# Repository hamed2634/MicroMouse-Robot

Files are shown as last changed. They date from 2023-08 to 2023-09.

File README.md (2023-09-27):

# Micromouse Project 🤖

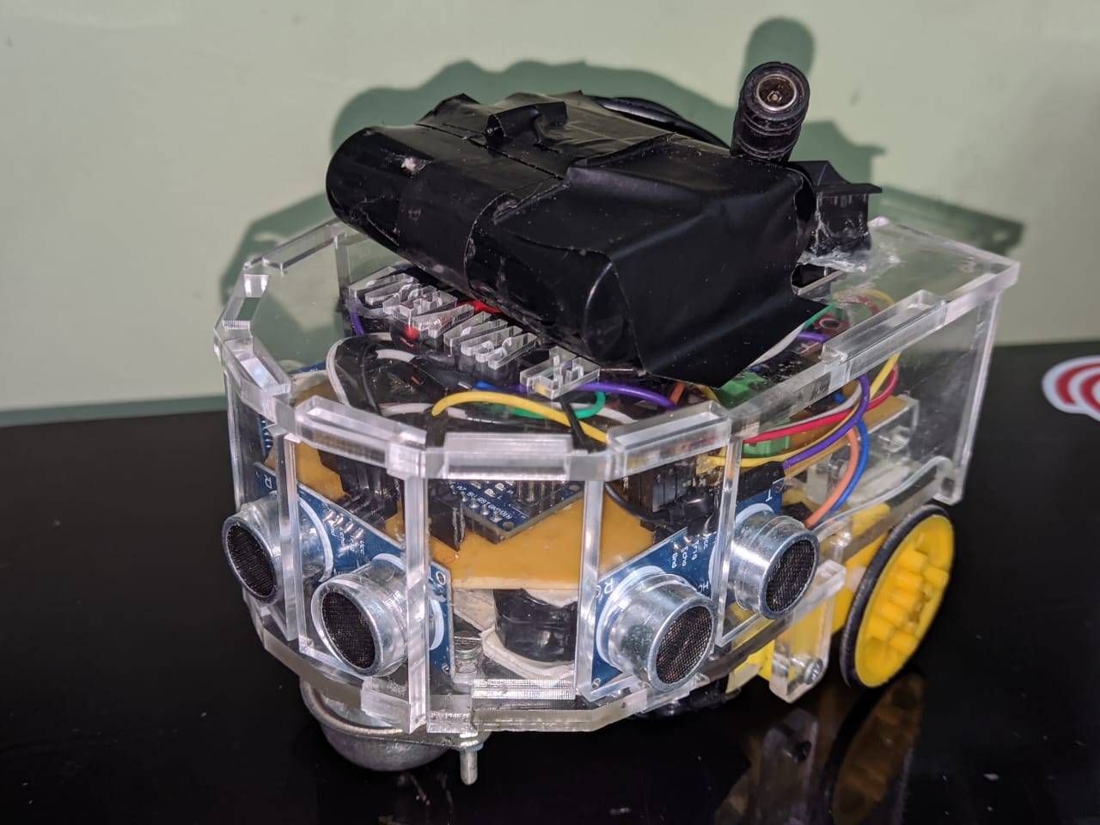
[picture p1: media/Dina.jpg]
Micromouse Robot


Welcome to the Micromouse project repository! This project showcases a small autonomous robot designed for maze navigation. Explore this project if you're interested in robotics and autonomous systems.

## Table of Contents
- [Hardware Components](#hardware-components-%EF%B8%8F)
- [Software](#software-)
  - [Controlling the Robot](#controlling-the-robot-)
  - [Algorithms](#algorithms-)
- [Team](#team-)
- [Installation](#installation-)
- [Contributing](#contributing-)
- [Contact](#contact-)

## Hardware Components 🛠️

The Micromouse project utilizes the following hardware components:

### PCB (Printed Circuit Board) 🧩
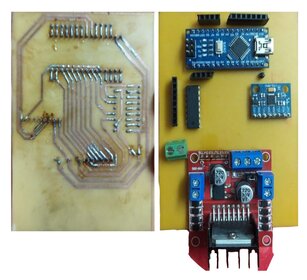
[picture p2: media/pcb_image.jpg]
PCB


The central control hub that connects and manages all other components.

You can find all details and schematic [Here](https://oshwlab.com/om4rr/micromouse).

### Ultrasonic Sensor 🦇
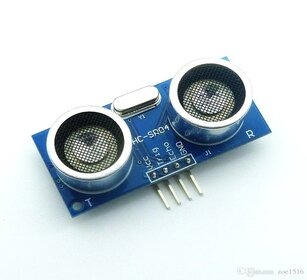
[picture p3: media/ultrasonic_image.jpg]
Ultrasonic Sensor


Measures distances and detects obstacles for navigation.

### IR Sensor (Infrared Sensor) 🕵️
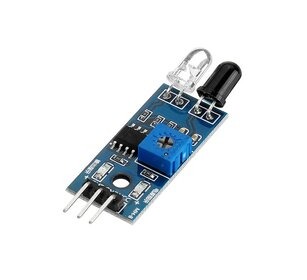
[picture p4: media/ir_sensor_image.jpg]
IR Sensor


Detects lines and walls for precise navigation in mazes.

### Optical Encoder 🔍
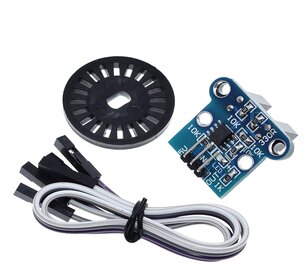
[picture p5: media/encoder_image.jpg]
Optical Encoder


Tracks wheel movements for accurate control.

### Wheels 🚗
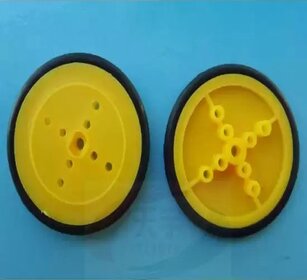
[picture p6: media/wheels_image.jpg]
Wheels and Chassis


The wheels of the robot.

### 3D Design 🖨️

We have designed a custom 3D chassis for the robot using Fusion 360. Here's a photo of our 3D design:

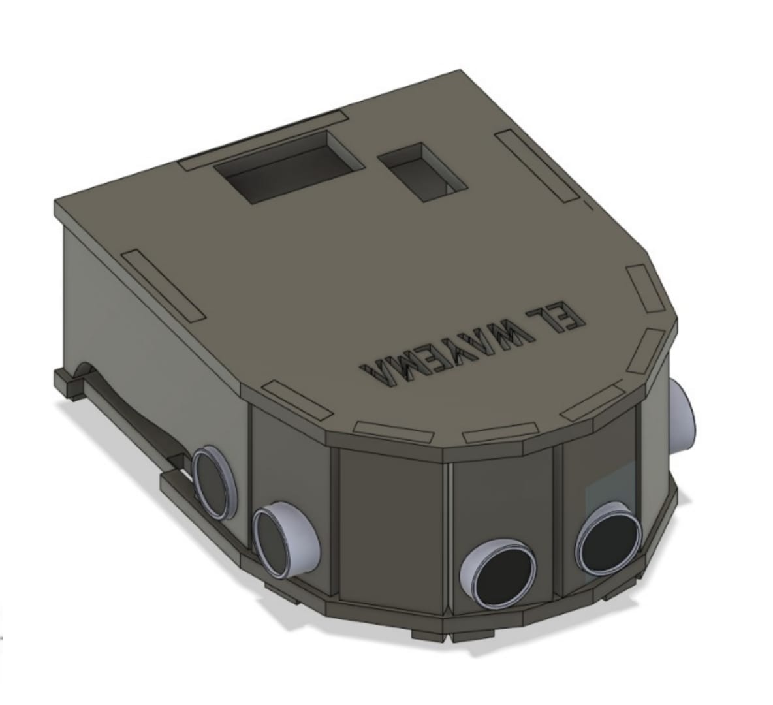
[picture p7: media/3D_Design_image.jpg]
3D Design


For More Photos click [Here](Design/images)

### Bluetooth Module 📶
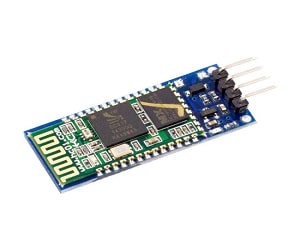
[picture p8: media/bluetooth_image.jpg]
Bluetooth Module


Allows remote debugging and control for monitoring the robot.

### Motors 🔄
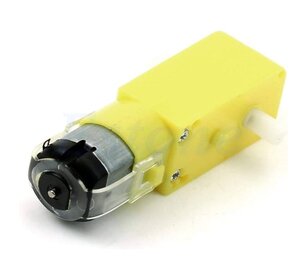
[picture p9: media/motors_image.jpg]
Motors


Drive the wheels for movement.

### Freewheel (Caster Wheel) 🎡
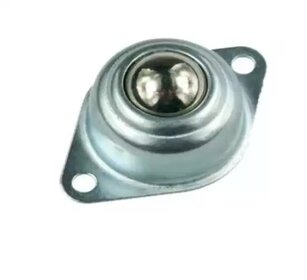
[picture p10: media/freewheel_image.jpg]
Freewheel


Provides stability and maneuverability during turns.

### Gyroscope (MPU6050) 🧭
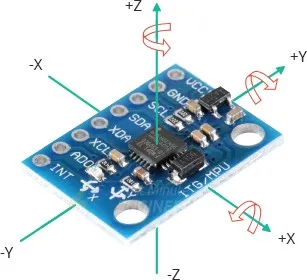
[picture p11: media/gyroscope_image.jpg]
Gyroscope


Measures angles and helps maintain orientation for accurate navigation.

## Software 🧾

### Controlling the Robot 🎮

#### Angle Control with PD System 📐

We've implemented a PD (Proportional-Derivative) control system for angle control using the Gyroscope (MPU6050) as the feedback element. The primary goal of this system is to keep the robot moving in a straight line and execute precise 90-degree turns when needed.

- **Proportional (P):** The proportional part of the controller ensures that the desired angle remains static, allowing the robot to move in a straight line.

   Functionality: When P is adjusted, it affects how quickly the robot corrects deviations from a straight path.

- **Derivative (D):** The derivative part helps fine-tune the turning process.

   Functionality: Tuning D affects how the robot responds to deviations in the angle, contributing to stable and precise turns.

For graphs and visualizations of the tuning process, please click [Graphs](Testing/PID_CALC/Graphs) to access the response graphs.

#### Sensor Reading 📡

To navigate the maze effectively, the robot continuously reads sensors located in every cell. Here's how the sensors work:

- **Ultrasonic Sensors:** These sensors detect obstacles, specifically walls, by measuring distances. This information helps the robot avoid collisions and navigate around maze walls.

- **IR Sensors (Infrared Sensors):** While the robot is designed to move in a straight line, minor alignment issues can occur. The IR sensors play a crucial role in detecting deviations from a straight path. If an IR sensor reads a signal, it indicates that the robot is getting too close to a wall.

   Functionality: In response to IR sensor readings, we make minor adjustments to the desired angle, typically by 5 degrees, to correct the alignment and maintain a straight path.

By combining precise angle control and sensor readings, our robot can successfully navigate the maze with accuracy and efficiency.

### Algorithms 🧠

The general idea for the algorithm is that it discovers the whole maze using the flood-fill algorithm and collects the data needed to configure the shortest path using BFS.
The code is provided with comments to explain in detail this approach [Algorithm](Optimised_Algorithm/floodfill/floodfill.cpp).

#### Maze Simulation 🌀

You can watch a maze simulation in action below:

Maze Simulation (https://github.com/hamed2634/MicroMouse-Robot/assets/52867472/5dad4e3b-37f2-4e1f-a091-5508377ebc72)

## Team 👥

Meet the team members who contributed to this project:

- **[Hamed](https://github.com/Hamed2634):** Responsible for controlling the robot.

- **[3bkareem](https://github.com/3bkareem):** Responsible for algorithm development.

- **[om4rrr](https://github.com/om4rrr):** Responsible for PCB design and assembling hardware.

- **[Kareem](https://github.com/UwUKareem):** Responsible for 3D design.

## Installation 📥

1. You can download the latest version of the Micromouse project as a ZIP file by clicking [here](link_to_zip_file.zip).

## Contributing 🤝

While this project primarily serves as a showcase, we welcome suggestions and improvements. Feel free to create issues or send pull requests.

## Contact 📧

For inquiries or to get in touch, you can reach us at [hamed.mohamed26324@gmail.com]. Enjoy exploring the Micromouse project! 🤖🚀

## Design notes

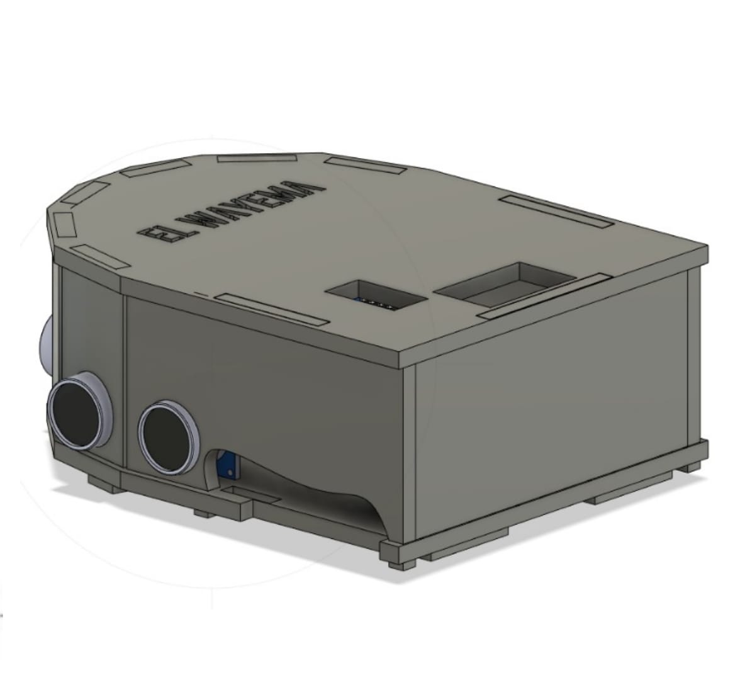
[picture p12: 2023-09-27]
Design/images/3D_Design_1_image.jpg

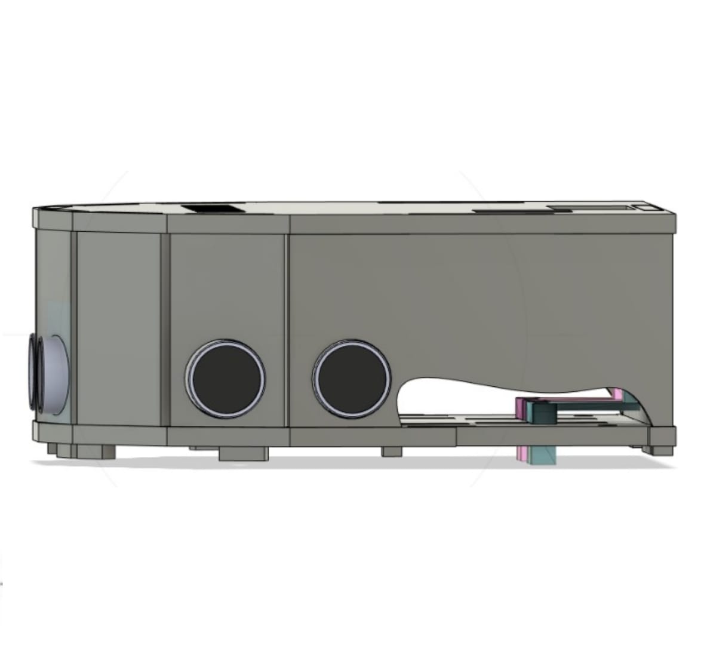
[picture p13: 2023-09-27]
Design/images/3D_Design_2_image.jpg

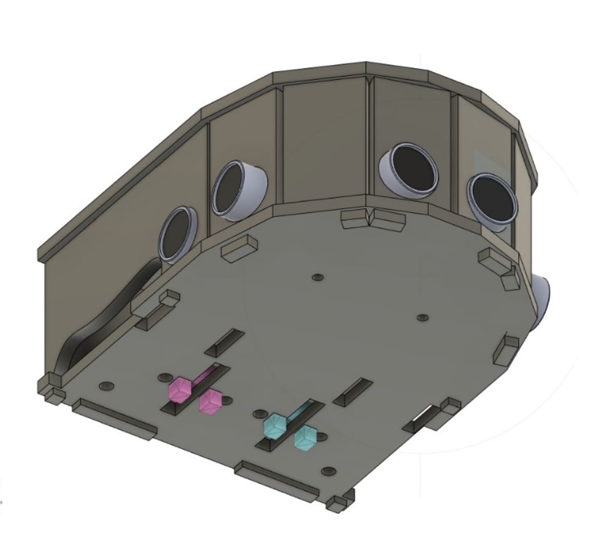
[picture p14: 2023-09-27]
Design/images/3D_Design_4_image.jpg

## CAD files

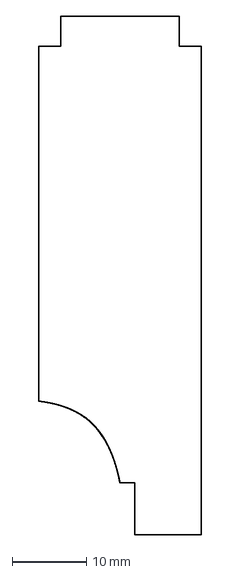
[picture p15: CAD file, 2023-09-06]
Design/side 4.dxf
22.0 x 70.0 mm

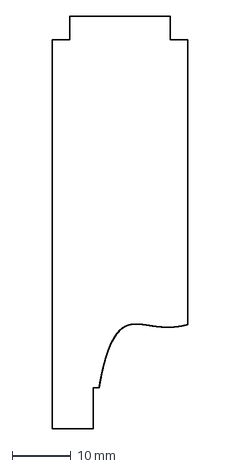
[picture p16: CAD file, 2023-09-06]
Design/side 3.dxf
23.0 x 70.0 mm

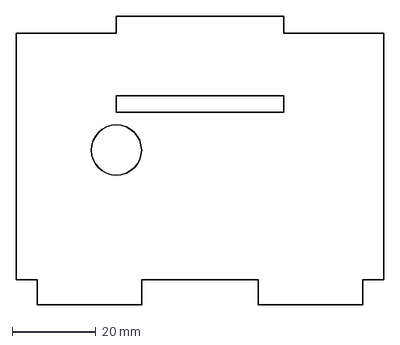
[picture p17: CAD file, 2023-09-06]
Design/back.dxf
88.0 x 69.0 mm

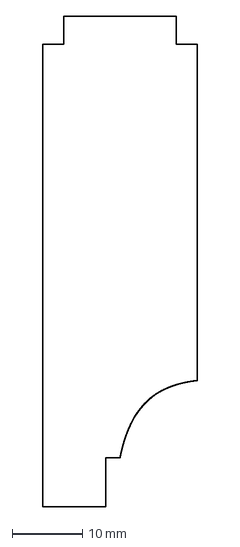
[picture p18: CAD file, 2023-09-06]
Design/side 5.dxf
22.0 x 70.0 mm

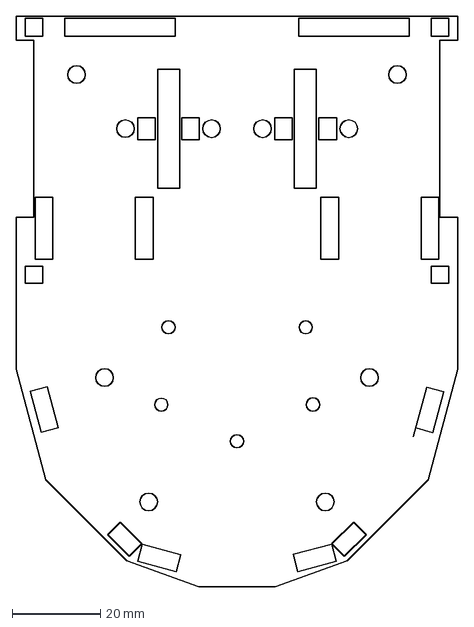
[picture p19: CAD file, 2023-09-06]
Design/frist floor .dxf
100.0 x 129.2 mm

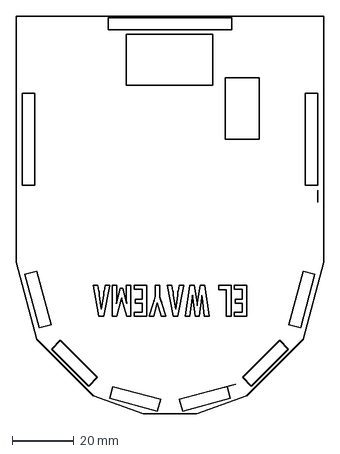
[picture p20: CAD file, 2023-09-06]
Design/third floor.dxf
100.0 x 129.2 mm

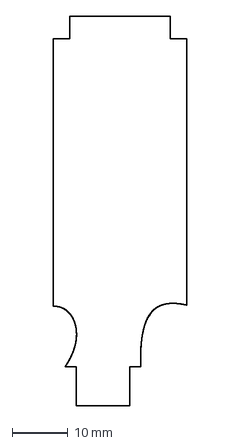
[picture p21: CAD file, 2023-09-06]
Design/side 7.dxf
24.0 x 70.0 mm

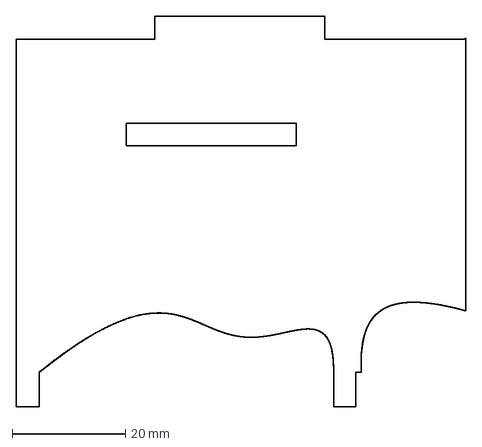
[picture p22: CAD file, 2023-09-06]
Design/side 8.dxf
79.5 x 69.0 mm

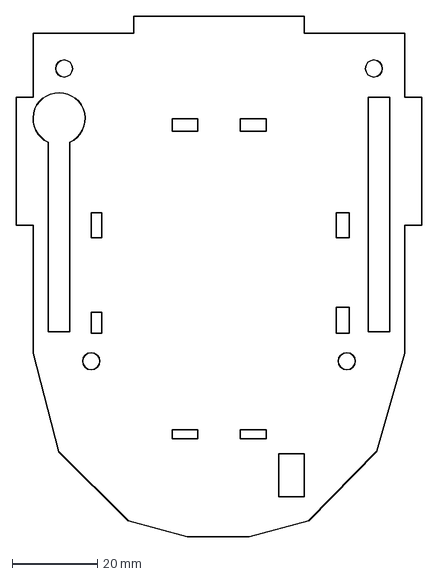
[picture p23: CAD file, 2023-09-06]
Design/second floor.dxf
95.0 x 122.0 mm

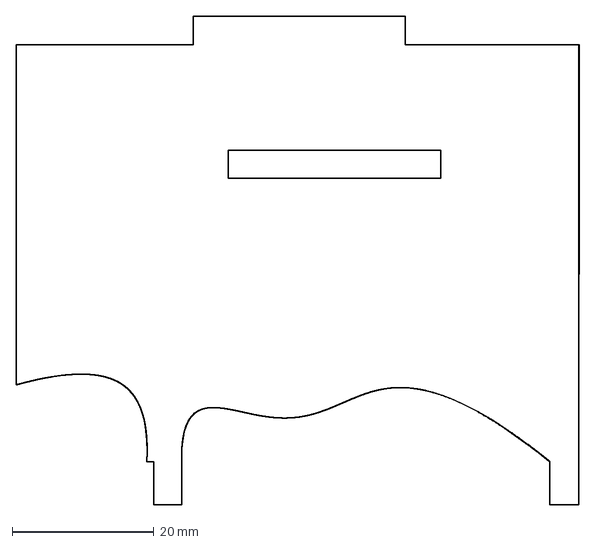
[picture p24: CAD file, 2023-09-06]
Design/side 1.dxf
79.5 x 69.0 mm

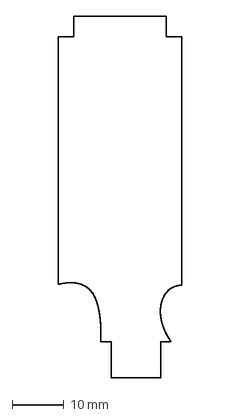
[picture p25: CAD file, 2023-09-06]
Design/side 2.dxf
24.0 x 70.0 mm

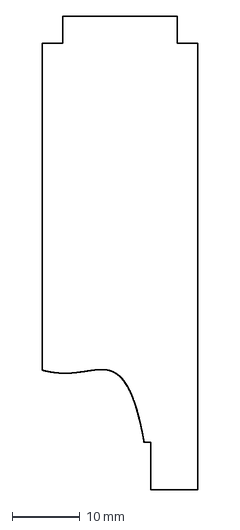
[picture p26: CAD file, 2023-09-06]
Design/side 6.dxf
23.0 x 70.0 mm

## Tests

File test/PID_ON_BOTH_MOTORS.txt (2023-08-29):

  float RightKp = 7.1000, LeftKp = 5.1000, RightKd = 100.00000, LeftKd = 100.00000;
  float DesiredDistance = 100.00;
  float RightDistanceError = DesiredDistance - RightCount * 21.50/40.00;
  float LeftDistanceError = DesiredDistance - LeftCount * 21.50/40.00;
  float RightOutput = RightKp * RightDistanceError + RightKd * (RightDistanceError - LastRightDistanceError);
  float LeftOutput = LeftKp * LeftDistanceError + LeftKd * (LeftDistanceError - LastLeftDistanceError);

  LastRightDistanceError = RightDistanceError;
  LastLeftDistanceError = LeftDistanceError; 

  AddToRightSpeed(RightOutput);
  AddToLeftSpeed(LeftOutput);

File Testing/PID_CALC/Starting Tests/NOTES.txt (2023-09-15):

Kp
1 ---> UNstaple
0.1 --> stable and slow
0.5 --> unstable over time
0.12->stable

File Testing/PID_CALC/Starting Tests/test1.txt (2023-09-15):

0.00 30.00 30.00
0.00 60.00 60.00
0.00 90.00 90.00
0.00 120.00 120.00
0.00 150.00 150.00
0.00 180.00 180.00
0.00 210.00 210.00
0.00 240.00 240.00
0.00 255.00 255.00
0.00 255.00 255.00
0.00 255.00 255.00
0.00 255.00 255.00
0.00 255.00 255.00
0.00 255.00 255.00
0.00 255.00 255.00
-0.02 255.00 255.00
-0.03 255.00 255.00
-0.06 255.00 255.00
-0.07 255.00 255.00
-0.09 255.00 255.00
-0.11 255.00 255.00
-0.12 255.00 255.00
-0.14 255.00 255.00
-0.15 255.00 255.00
-0.17 255.00 255.00
-0.19 255.00 255.00
-0.21 255.00 255.00
-0.21 255.00 255.00
-0.21 255.00 255.00
-0.21 255.00 255.00
-0.21 255.00 255.00
-0.21 255.00 255.00
-0.21 255.00 255.00
-0.21 255.00 255.00
-0.21 255.00 255.00
-0.21 255.00 255.00
-0.21 255.00 255.00
-0.22 255.00 255.00
-0.24 255.00 255.00
-0.25 255.00 255.00
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

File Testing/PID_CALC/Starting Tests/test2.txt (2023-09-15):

04:02:09.843 12.86 ‑17.46 17.46 450.00
04:02:09.846 11.53 ‑9.00 9.00 450.00
04:02:09.880 10.22 ‑0.51 0.51 450.00
04:02:09.880 8.92 7.99 ‑7.99 450.00
04:02:09.881 7.37 18.30 ‑18.30 450.00
04:02:09.881 6.35 24.96 ‑24.96 450.00
04:02:09.881 5.11 33.30 ‑33.30 450.00
04:02:09.884 3.90 41.49 ‑41.49 450.00
04:02:09.884 2.74 49.46 ‑49.46 450.00
04:02:09.888 1.61 57.26 ‑57.26 450.00
04:02:09.888 0.52 64.86 ‑64.86 450.00
04:02:09.915 ‑0.53 94.86 ‑34.86 450.00
04:02:09.915 ‑1.72 103.31 ‑43.31 450.00
04:02:09.915 ‑2.65 110.00 ‑50.00 450.00
04:02:09.918 ‑3.51 116.28 ‑56.28 450.00
04:02:09.918 ‑4.31 122.13 ‑62.13 450.00
04:02:09.947 ‑5.03 127.52 ‑67.52 450.00
04:02:09.947 ‑5.67 132.43 ‑72.43 450.00
04:02:09.949 ‑6.22 136.73 ‑76.73 450.00
04:02:09.949 ‑6.70 140.51 ‑80.51 450.00
04:02:09.951 ‑7.09 143.77 ‑83.77 450.00
04:02:09.953 ‑7.47 146.94 ‑86.94 450.00
04:02:09.953 ‑7.71 149.14 ‑89.14 450.00
04:02:09.981 ‑7.86 150.80 ‑90.80 450.00
04:02:09.981 ‑7.95 151.97 ‑91.97 450.00
04:02:09.982 ‑7.95 152.52 ‑92.52 450.00
04:02:09.982 ‑7.89 152.62 ‑92.62 450.00
04:02:09.985 ‑7.75 152.21 ‑92.21 450.00
04:02:09.986 ‑7.54 151.29 ‑91.29 450.00
04:02:09.986 ‑7.21 149.49 ‑89.49 450.00
04:02:10.027 ‑6.88 147.60 ‑87.60 450.00
04:02:10.027 ‑6.48 145.26 ‑85.26 450.00
04:02:10.027 ‑6.01 142.42 ‑82.42 450.00
04:02:10.027 ‑5.49 139.18 ‑79.18 450.00
04:02:10.030 ‑4.92 135.54 ‑75.54 450.00
04:02:10.030 ‑4.30 131.48 ‑71.48 450.00
04:02:10.032 ‑3.63 127.02 ‑67.02 450.00
04:02:10.034 ‑2.76 121.15 ‑61.15 450.00
04:02:10.034 ‑1.99 115.91 ‑55.91 450.00
04:02:10.061 ‑1.18 110.31 ‑50.31 450.00
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

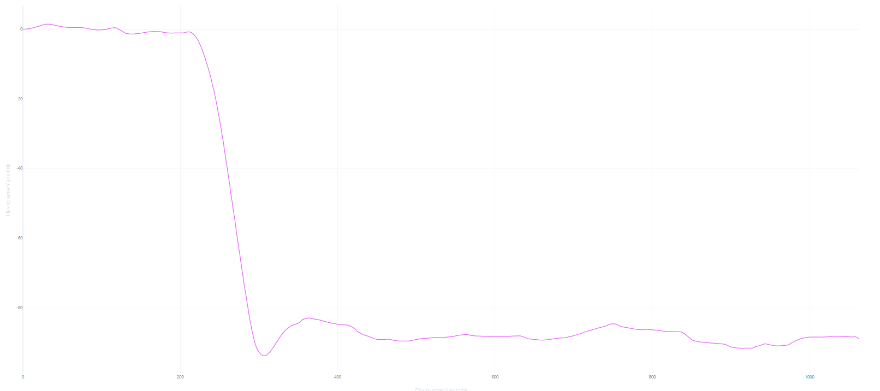
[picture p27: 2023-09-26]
Testing/PID_CALC/Graphs/kp0.07,kd7.png

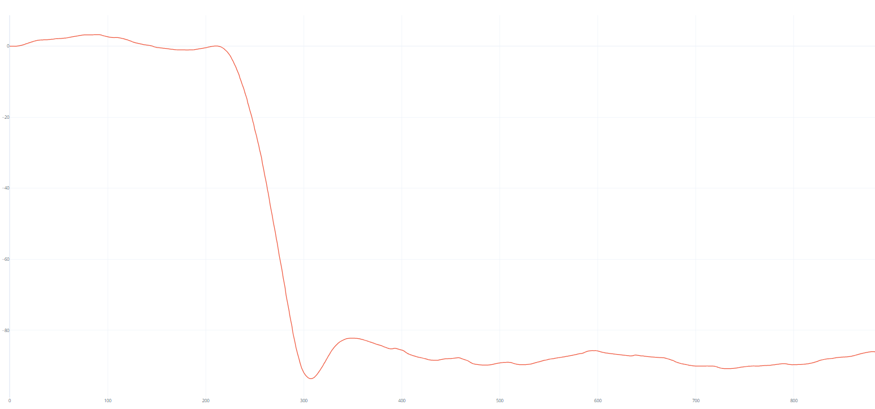
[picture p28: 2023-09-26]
Testing/PID_CALC/Graphs/kp0.05.png

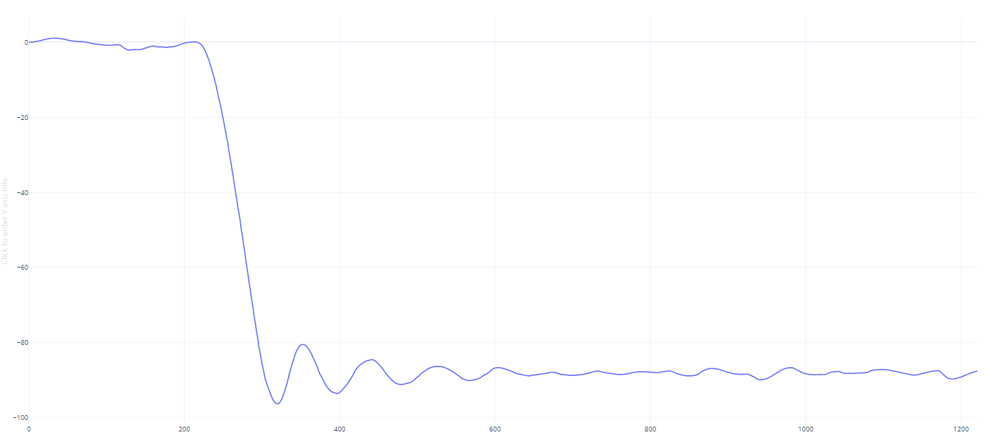
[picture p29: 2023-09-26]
Testing/PID_CALC/Graphs/kp0.07,kd15.png

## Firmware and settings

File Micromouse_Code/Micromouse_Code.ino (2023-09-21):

#include "Micromouse_Code.h"
extern int Count;
bool turned = 0;
bool turn2 = 0;
bool Sensed = 0;
extern NewPing LeftUltra,RightUltra,FrontUltra;
extern float AngleZ;
int ping = 20;

void loop() {
  MoveFromCenterToSensing();
  ReadWallsUltra();
  if(wallRight() && wallFront() && wallLeft()) {
    TurnLeft();
    TurnLeft();
    BrakeFromSensingToCenter();
  }
  else if(wallRight() && wallFront()){
    BrakeFromSensingToCenter();
    TurnLeft();
  }
  else if(wallRight()){
    BrakeFromSensingToCenter();
  }
  else {
    BrakeFromSensingToCenter();
    TurnRight();
  }



  // MoveFromCenterToSensing();
  // ReadWallsUltra();
  // BrakeFromSensingToCenter();
  // TurnRight();
  // MoveFromCenterToSensing();
  // ReadWallsUltra();
  // BrakeFromSensingToCenter();
  // TurnLeft();
  // MoveFromCenterToSensing();
  // ReadWallsUltra();
  // BrakeFromSensingToCenter();
  // stop();
  // delay(500000000);


  // forward();
  //  MoveFromSensingToCenter();
  // BrakeFromSensingToCenter();

  // //Take UltraSonic Reads


  // //if moveforward with out turns
  // //else 
  // Serial.println(GetDistance());
  // Serial.println(GetDistance());
  // for(int i = 1 ; i < 1000 ;i++){
  //   ReadEncoder();
  //   delay(1);
  // }
  // Serial.println(GetDistance());



  //timer++;
  //doIt();
  // ReadGyro();
  // ReadEncoder();
  // if(timer > 50) {
  //   ReadWallsUltra();
  //   Serial.print(wallLeft());
  //   Serial.print(" ");
  //   Serial.print(wallFront());
  //   Serial.print(" ");
  //   Serial.print(wallRight());
  //   Serial.println();
  //   timer = 0;
  // }
  //Serial.println(AngleZ);
  //Serial.print(" ");
   //Serial.println(GetDistance());
  // Serial.print(LeftUltra.ping_cm());
  // Serial.print(" ");
  // Serial.print(FrontUltra.ping_cm());
  // Serial.print(" ");
  // Serial.print(RightUltra.ping_cm());
  // Serial.println();
  //MoveStraightUltra();

  // if(GetDistance() > CellWidth) {
  //   Count = 0;
  //   Sensed = 0; 
  //   //TakeDecision of Rotating
  // }

  // if(!Sensed && GetDistance() > StartToCenter) {
  //   //ReadWallsUltra();
  //   Sensed = 1;
  //   // Serial.print(LeftUltra.ping_cm());
  //   // Serial.print(" ");
  //   // Serial.print(FrontUltra.ping_cm());
  //   // Serial.print(" ");
  //   // Serial.println(RightUltra.ping_cm());
  // } 


  // if(GetDistance() > 53 && !turned) {
  //   TurnLeft();
  //   MoveCellForward();
  //   TurnRight();
  //   turned = 1;
  //   Count = 0;
  // }
  //188
  // if(GetDistance() > 170 && !turn2){
  //   TurnRight();
  //   TurnRight();
  //   turn2 = 1;
  // }
  // if(wallRight() && wallFront() && wallLeft()) {
  //   TurnLeft();
  //   TurnLeft();
  //   timer = 100;
  // }
  // else if(wallRight() && wallFront()){
  //   TurnLeft();
  //       timer = 100;

  // }
  // else if(wallRight()){
  //   MoveStraight();
  // }
  // else {
  //   TurnRight();
  //       timer = 100;
  // }



  // ReadGyro();
  // MoveStraight();
  // ReadWallsUltra();
  // if(wallRight()) {
  //   if(wallFront()) { 
  //     TurnLeft();
  //     MoveCellForward();
  //   }
  //   else {
  //     MoveStraight();
  //   }
  // }
  // else {
  //   TurnRight();
  //   MoveCellForward();
  // }








  // ReadEncoder();
  // if(GetDistance() > 70) {
  //   stop();
  //   delay(5000000);
  // }

//  MoveStraight();
    // ReadEncoder();
    // Serial.print(Count);
    // Serial.print(" ");
    // Serial.println(GetDistance());
    // if(Serial.available()){
    //   Serial.read();
    //   Count = 0;
    // }



  
  


}

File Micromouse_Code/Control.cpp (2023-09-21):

#include "Control.h"

float GyroRatio = 352.3333/360;

extern float AngleZ, ZError; // declare Z, ZError to assign Angle of yaw and error of it..
float LastAngleError = 0, DesiredAngle = 0;
extern volatile int Count; 
extern float RightSpeed , LeftSpeed;
int FatalSensorTimer = 0;

void MoveStraight() {

    // /*              FeedForward             */
    int DesiredSpeed = 125;
    float KpSpeed = 0.05;
    float SpeedError = DesiredSpeed - (LeftSpeed + RightSpeed)/2.0;

    int SpeedOutput = KpSpeed * SpeedError;

    /*        PID On Angle -- PD Controller         */
    float kpAng = 0.03, kdAng = 5, AngleOutput = 0, AngleError = DesiredAngle - AngleZ;
    AngleOutput = kpAng * AngleError + kdAng * (AngleError - LastAngleError) ;

    AddToRightSpeed(SpeedOutput + AngleOutput,MAXSPEED);
    AddToLeftSpeed(SpeedOutput + -1 * AngleOutput, MAXSPEED);

    LastAngleError = AngleError;
    //Debug5(AngleZ, DesiredAngle, LeftSpeed , RightSpeed , AngleOutput);
}


void TurnRight() {

    StopSlowly(); // decrease speed to turn smooth

    DesiredAngle -= 90 * GyroRatio;
    float AngleError = DesiredAngle - AngleZ;

    while(fabs(AngleError) > 10) {
        ReadGyro();
        /*          pid On angle -- pcontroller            */
        // float kpAng = 0.2, kdAng = 10;
        float kpAng = 0.05, kdAng = 5; // best const..
        //float kpAng = 0.03, kdAng = 5; 
        // float kpAng = 0.15, kdAng = 15;
        AngleError = DesiredAngle - AngleZ;
        float AngleOutput = kpAng * AngleError + kdAng * (AngleError - LastAngleError) ;
        AddToRightSpeed(AngleOutput,MAXTURNSPEED);
        AddToLeftSpeed(-1 * AngleOutput,MAXTURNSPEED);
        LastAngleError = AngleError;
        // Debug5(z, DesiredAngle, LeftSpeed , RightSpeed , AngleOutput);
    }

    forward();
}

void TurnLeft() {

  StopSlowly(); // decrease speed to turn smooth

    DesiredAngle += 90 * GyroRatio;
    float AngleError = DesiredAngle - AngleZ;
    
    while(fabs(AngleError) > 1) {
        ReadGyro();
        /*          pid On angle -- pcontroller            */
        float kpAng = 0.05  , kdAng = 5;
        AngleError = DesiredAngle - AngleZ;
        float AngleOutput = kpAng * AngleError + kdAng * (AngleError - LastAngleError) ; // negative
        AddToRightSpeed(AngleOutput, MAXTURNSPEED);
        AddToLeftSpeed(-1 * AngleOutput, MAXTURNSPEED);
        LastAngleError = AngleError;
        //Debug5(z,DesiredAngle,AngleError, LeftSpeed - AngleOutput, RightSpeed + AngleOutput);
    }

    forward();
}

void TurnAround(){
    StopSlowly();

    DesiredAngle += 180 * GyroRatio;
    float AngleError = DesiredAngle - AngleZ;

    while(fabs(AngleError) > 1){
        ReadGyro();
        /*          pid On angle -- pcontroller            */
        float kpAng = 0.01  , kdAng = 0.1;
        AngleError = DesiredAngle - AngleZ;
        float AngleOutput = kpAng * AngleError + kdAng * (AngleError - LastAngleError) ;
        AddToRightSpeed(AngleOutput, MAXTURNSPEED);
        AddToLeftSpeed(-1 * AngleOutput, MAXTURNSPEED);
        LastAngleError = AngleError;
        //Debug5(z,DesiredAngle,AngleError, LeftSpeed - AngleOutput, RightSpeed + AngleOutput);
    }
    forward();
}


void MoveCellForward(){
    int Timer = 0;
    while(Timer < 1500){
        MoveStraight();
        Timer++;
    }
    return;
}

void MoveFromStartToCenter(){
    Count = 0;
    while(GetDistance() < StartToCenter){
        ReadGyro();
        ReadEncoder();
        MoveStraight();
    }
    return;
}

void AdjustAlignment() {
    backward();
    AngleZ = DesiredAngle;
    delay(200);
    MoveToCenter();
    return;
}

void MoveFromCenterToSensing(){
  Count = 0;
  while(GetDistance() < CenterToSensing){
    ReadGyro();
    ReadEncoder();
    MoveStraight();
  }
}

void MoveFromSensingToCenter(){
  Count = 0;
  while(GetDistance() < SensingToCenter){
    ReadGyro();
    ReadEncoder();
    MoveStraight();
  }
}

void BrakeFromSensingToCenter(){
  Count = 0;
  while(GetDistance() < AccDistance(SensingToCenter)){
    ReadGyro();
    ReadEncoder();
    MoveStraight();
  }
  stop();
  Count = 0;
  // while(GetDistance() < SensingToCenter){
  //   ReadGyro();
  //   ReadEncoder();
  //   static float LastDistanceError = 0;
  //   float Kp = 0, Kd = 93.75;
  //   float DistanceError = SensingToCenter - GetDistance();
  //   float DistanceOutput = Kp * DistanceError + Kd * (DistanceError - LastDistanceError); 
  //   LastDistanceError = DistanceError;
  //   AddToLeftSpeed(DistanceOutput,MAXSPEED);
  //   AddToRightSpeed(DistanceOutput,MAXSPEED);
  // }
}

void ControlFatalsensors() {
  FatalSensorTimer++;
  if(FatalSensorTimer > 100){
      ReadIR();
    if(GetLeftFatal() && !GetRightFatal()) {
      DesiredAngle -= 5 * GyroRatio;
    }
    if(GetRightFatal() && !GetLeftFatal()) {
      DesiredAngle += 5 * GyroRatio;
    }
    FatalSensorTimer = 0;
  }
  //Debug2(GetLeftFatal(), GetRightFatal());
}

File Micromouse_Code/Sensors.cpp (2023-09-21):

#include "Sensors.h"

/*          gyroscope variables            */
Adafruit_MPU6050 mpu;
sensors_event_t a, g, temp;
float AngleZ = 0, ZError = 0;

/*          Integration varibles           */
float LastTime = 0, Time, dt, Area;

/*         Encoder Variables               */
bool LastEncoderState = 0;
volatile int Count = 0; 

/*               UltraSonic                */
NewPing LeftUltra = NewPing(LeftTrigger, LeftEcho, MAX_MEASURED_DISTANCE); // Each sensor's trigger pin, echo pin, and max distance to ping.
NewPing FrontUltra = NewPing(FrontTrigger, FrontEcho, MAX_MEASURED_DISTANCE);
NewPing RightUltra = NewPing(RightTrigger, RightEcho, MAX_MEASURED_DISTANCE);
int UltraTimer = 0;


char Wall_Readings = 0, FatalReadings = 0; // L - L45 - F - R45 - R

// GYROSCOPE INITIALIZE
void GyroScopeInit() {

  // Try to initialize!

  mpu.begin();
  mpu.setAccelerometerRange(MPU6050_RANGE_8_G);
  mpu.setGyroRange(MPU6050_RANGE_500_DEG);
  mpu.setFilterBandwidth(MPU6050_BAND_5_HZ);

  // calibration
  for(int i = 0; i < 200; ++i) {
    mpu.getEvent(&a, &g, &temp);
    ZError += g.gyro.z;
  }
  ZError /= 200.0;
}


// ALL SENSORS READINGS
void ReadGyro() {
  mpu.getEvent(&a, &g, &temp);
  Time = millis();
  dt = Time - LastTime;
  Area = (g.gyro.z - ZError) * dt/1000.0 * 180/M_PI;
  if(fabs(Area) > 0.01) AngleZ += Area;
  LastTime = Time;
}


void ReadEncoder() {
  bool State = digitalRead(Encoder);
  Count += State^LastEncoderState;
  LastEncoderState = State;
}

void ReadIR() {
  if(!digitalRead(LeftFatalSensor)) setbit(FatalReadings, 0);
  else clrbit(FatalReadings, 0);

  if(!digitalRead(RightFatalSensor)) setbit(FatalReadings, 1);
  else clrbit(FatalReadings, 1);
}


void ReadWallsUltra() {
  if(LeftUltra.ping_cm() < MAX_ALLOWED_Horiz_DISTANCE) setbit(Wall_Readings,1);
  else clrbit(Wall_Readings,1); 

  if(FrontUltra.ping_cm() < MAX_ALLOWED_Vert_DISTANCE) setbit(Wall_Readings,2);
  else clrbit(Wall_Readings,2); 

  if(RightUltra.ping_cm() < MAX_ALLOWED_Horiz_DISTANCE) setbit(Wall_Readings,3);
  else clrbit(Wall_Readings,3); 
}

bool wallFront() {
  return getbit(Wall_Readings,2);
}

bool wallRight() {
  return getbit(Wall_Readings,3);
}

bool wallLeft() {
  return getbit(Wall_Readings,1);
}

float AccDistance(float x){
  return  x/0.973 - 3.3985/0.973;
}
float GetDistance() {
  return Count/40.0 * 3.94*PI;
}

bool GetRightFatal() {
  return getbit(FatalReadings,1);
}

bool GetLeftFatal() {
  return getbit(FatalReadings,0);
}

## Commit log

2023-08-27 added wheel design
    [wheel.SLDPRT]
2023-08-29 gyro test
2023-08-29 GyroScope Test Done :)
2023-09-06 Added Micromouse Design
    [back.dxf, frist floor .dxf, second floor.dxf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]
2023-09-10 Added Turns and PID on Angle
2023-09-15 Calculated PID Terms
    [0,1.xlsx, 0,12.log.xlsx, 0,12plowdamping,.log.xlsx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]
2023-09-17 Feed Forward and Tuned PID Constants
    [0,1.xlsx, kp0,009andkd0,002.xlsx, kp0,03andkd0,006.xlsx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]
2023-09-18 added algorithm
    [0,1.xlsx, 0,12.log.xlsx, 0,12plowdamping,.log.xlsx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]
2023-09-24 added updates
    [0,1.xlsx, 0,12.log.xlsx, 0,12plowdamping,.log.xlsx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]
2023-09-24 added pcb image
2023-09-26 Added graphs to pid calc
